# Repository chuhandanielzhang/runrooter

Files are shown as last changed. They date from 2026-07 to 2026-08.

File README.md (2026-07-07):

# Hopper robot runtime (collected runnable files)

This folder gathers the **actually-running** files of the Hopper stack (lower layer +
upper layer + IMU bridge + bring-up scripts). It is a curated copy of the live sources;
build artifacts, logs, caches, and analysis/plot scripts were left out.

## Architecture

```
   PC (this machine)                         Jetson (nvidia@192.168.1.100)
 ┌─────────────────────┐   LCM (multicast)  ┌──────────────────────────────┐
 │ run_modee.py         │ <───────────────> │ hopper_driver (legs/CAN/pad)  │  hopper-driver.service
 │  ModeECore + WBC-QP  │  hopper_data_lcmt  │   src/hardware/*.cpp          │
 │  propeller/leg cmd    │  hopper_imu_lcmt   │                              │
 │                       │  gamepad_lcmt      │ px4_bridge.py (USB MAVLink)  │  px4-bridge.service
 │                       │  motor_pwm_lcmt    │   props=USB  IMU=DDS/TELEM2  │
 └─────────────────────┘                    │  (split: IMU 500, prop 150)  │
                                             │ canable (can0 bring-up)      │  canable.service
                                             └──────────────────────────────┘
```

- **Legs**: 3× AK60 over SocketCAN (`can0`).
- **IMU + propellers**: on the Pixhawk (PX4). As of 2026-07-01 this uses the **SPLIT path**:
  - **IMU** over **DDS/TELEM2** @ **500 Hz**: `xrce-agent.service` (Micro-XRCE-DDS Agent on
    `/dev/ttyTHS1`) + `px4-dds-bridge.service` (`px4_dds_bridge.py --mount-rpy 0,90,0
    --publish-hz 500`) publishes `hopper_imu_lcmt` from PX4 DDS topics. Dedicated UART =
    contention-free. (IMU mount/coordinate unchanged from before — only comms changed.)
  - **Props** over **USB MAVLink**: `px4-bridge.service` runs `px4_bridge.py --no-imu`
    (props ONLY), streaming `MAV_CMD_DO_SET_ACTUATOR` from `motor_pwm_lcmt`. The PC still
    publishes `motor_pwm_lcmt` at the full **500 Hz** control rate, but the MAVLink
    re-stream is capped at **150 Hz** (`--prop-rate 150`): PX4 answers EVERY
    `DO_SET_ACTUATOR` with a `COMMAND_ACK` on this same USB link, so 400 Hz+ floods the link
    with ACKs, PX4 throttles/drops, and the actuator outputs FREEZE ("pwm stuck"). This cap
    is set by the ACK return traffic, NOT by whether the IMU shares the link — 150 Hz
    (6.7 ms) is still far faster than the prop time constant (~40 ms).
  - **Important**: `px4-bridge` MUST keep `--no-imu` so it does NOT also publish
    `hopper_imu_lcmt` — two publishers on one channel fight. To collapse back onto a single
    USB link (props+IMU), drop `--no-imu` and stop `px4-dds-bridge`/`xrce-agent` (keep
    `--prop-rate 150`).
- **Prop output wiring note (2026-06-30)**: the three props now live on the **AUX/FMU**
  group `AUX1/AUX2/AUX3` (moved off MAIN). PX4 output functions: `PWM_AUX_FUNC1=301`
  (Actuator Set 1 -> AUX1), `PWM_AUX_FUNC2=303` (Set3 -> AUX2), `PWM_AUX_FUNC3=302`
  (Set2 -> AUX3) — Set2/Set3 kept swapped so logical Set2/Set3 still drive the same
  physical props as before. `PWM_AUX_MIN/MAX/DIS 1/2/3 = 1000/2000/1000`. `PWM_MAIN_FUNC1/2/3`
  are now `0` (disabled). Driven by the controller via `MAV_CMD_DO_SET_ACTUATOR` (PWM, not
  DShot). NOTE: this Auterion PX4 1.14.3 build has **no `DSHOT_CONFIG` param** so DShot
  is not enable-able without reflashing stock PX4. Re-verify mapping with a per-Set
  low-power spin test after any rewire.

## Folder layout

| Folder | Runs on | What it is |
|---|---|---|
| `lower_driver_jetson/` | Jetson | C++ leg driver (`hopper_driver`). Build with `rebuild.sh`. Source = `Hopper_srbRL`. |
| `upper_controller_pc/` | PC | ModeE controller. `hopper_controller/run_modee.py` + `modee/`. `hopper_lcm_types/` kept as sibling so the `../../hopper_lcm_types/lcm_types` import resolves. |
| `imu_bridge_jetson/` | Jetson | SPLIT path: `px4_dds_bridge.py` (DDS/TELEM2 → `hopper_imu_lcmt` @500Hz) for IMU, `px4_bridge.py --no-imu` (USB MAVLink) for props (re-stream capped @150Hz). Launchers: `run_px4_dds_bridge.sh`, `run_xrce_agent.sh`, `run_px4_bridge.sh`. |
| `services/` | Jetson | systemd units: `hopper-driver`, `xrce-agent`, `px4-dds-bridge` (IMU/DDS), `px4-bridge` (props/USB, `--no-imu`). |
| `scripts/` | PC | `connect_and_start.sh` (one-shot lower-layer bring-up + LCM check) + `hopperleg_README.md`. |
| **`rlmujoco3rsr/`** | PC | **3-RSR 闭环 MuJoCo + MJX/Brax RL**（训练/评估/sim2sim/RL 部署）。见 `rlmujoco3rsr/README.md`。 |

## Bring-up

1. **Lower layer (Jetson)** — usually already installed as services. To (re)build the driver:
   ```bash
   cd lower_driver_jetson && ./rebuild.sh        # -> build/hopper_driver
   ```
   The services run `/home/nvidia/Hopper_srbRL/build/hopper_driver` etc.

2. **Bring everything up + verify (from PC)**:
   ```bash
   bash scripts/connect_and_start.sh             # SSHes to Jetson, starts services, checks CAN + LCM
   ```

3. **Upper layer (PC)**:
   ```bash
   cd upper_controller_pc/hopper_controller
   unset LD_LIBRARY_PATH
   python3 run_modee.py
   ```

## Gamepad map (current logic)

- **X** = enter PD (legs).  **A** = props ON (control_mode).  **B** = stop all (DAMP + props off).
- **LB** (only from the normal hopping cycle): arms a legs-only retraction. It actually
  starts on the **next flight phase, once the leg is back to its original length**
  (`|q_shift| <= switch_arm_l0_tol_m`), runs P1→P2→P3 and settles. A 2nd LB does nothing
  (one-way; use RB to return to hopping).
- **RB** (only after LB has settled at P3): position-controls the legs **up to
  `switch_rb_target_rad`** (P4), holds `switch_rb_settle_s`, then **enters the hopping
  cycle** (ModeE resumes). During the **first hop cycle** after RB (until the 2nd liftoff)
  the propeller PWM is floored at `hop_prop_base_pwm_us` (= 1200; props still spin only if A is ON).

Status line tags: `FLIGHT/STANCE` (normal), `+LB-ARM` (LB armed/waiting), `SW-LB-P1..3`
(retracting), `SW-LB-P3-DONE(RB?)` (settled, RB valid), `SW-RB-P4` (RB pull-up),
`+BASE1200` (post-RB prop base window).

## Key tunables

- Lower layer `qd`: published from a **2-sample central difference of the CAN position**
  (no heavy filtering), see `lower_driver_jetson/src/hardware/hopper_hardware.cpp`.
- Switch-loop / LB / RB / prop-base params: `ModeELCMConfig` at the top of
  `upper_controller_pc/hopper_controller/modee/lcm_controller.py`.

> Note: this is a **collected snapshot**, not a wired-up workspace. The Jetson-side pieces
> still build/run from `~/Hopper_srbRL` (and ROS `~/px4_ws`) on the robot; edit there (or
> sync) for live changes.

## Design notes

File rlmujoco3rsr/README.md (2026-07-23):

# 3-RSR 三旋翼并联跳跃机器人 — 仿真 / RL / Sim2Real 工作包

> **位置**: `robot_runtime/rlmujoco3rsr/`（从 `Hopper-mujoco-standalone/3RSR_package_2` 打包）
> **上层依赖**: 默认用同级 `../upper_controller_pc/`（可用 `CASE_REPO` 覆盖）
> **策略**: `policies/hop_policy_hwcal.params` 等 | **示例 GIF**: `demos/`

闭环并联腿(3-RSR)+ 三旋翼 的 aerial-legged hopper。本包包含 MuJoCo 模型、
MJX+PPO 强化学习训练、CPU 评估、以及通过 LCM 与 Cao(hopperHFAcase2026)上层
控制器互联做 sim2sim 交叉验证 / sim2real 部署的全部脚本。

---

## 1. 系统总览

```
                         ┌─────────────────────────────────────────┐
   高层 (model-based)     │  Cao ModeE SRB/质心 QP 控制器              │
   或 RL 任务策略          │  run_cao_on_our_model.py  /  RL 任务策略    │
                         └───────────────┬─────────────────────────┘
                                         │  LCM:hopper_cmd_lcmt (q_des,kp,kd)
                                         │      motor_pwm_lcmt   (6ch PWM)
                         ┌───────────────▼─────────────────────────┐
   被控对象 (plant)       │  cao_fake_robot.py  (我们的 MuJoCo 模型,     │
   仿真 或 真机           │  说 case 的 LCM 协议)  /  真实机器人 CAN桥     │
                         └───────────────┬─────────────────────────┘
                                         │  LCM:hopper_data_lcmt (q,qd)
                                         │      hopper_imu_lcmt   (quat,gyro)
                                         ▼
                              lcm-spy 可实时监看所有通道
```

两套控制可互换,都说同一套 LCM 协议:
- **Cao SRB QP**(model-based,已验证):`run_cao_on_our_model.py`
- **RL 策略**(本包训练):`rl_lcm_runner.py`

控制架构(分层 RL):
- **端到端策略** `train_hop.py` → `hop_policy_hwcal.params`(会跳,论文托底)
- **分层底层** `train_leg.py` → `leg_policy.params`(纯腿力/速度/腿长跟踪,配 SRB 高层)
- **空翻** `train_flip.py`(实验)

---

## 2. 模型 (`three_leg_3rsr_closed.xml`)

- **3-RSR 并联腿**:3 个髋电机 `ctrl_joint_1/2/3`,万向节被动副 `cross_pin+lower_pin`,
  足端经 `equality connect` 软约束闭环(MJX 原生闭环,非串联近似)。
- **三旋翼**:`prop1/2/3` 120° 对称;3 舵机绕外向 Z 倾转(矢量推力);反扭矩 `gear=±0.018`,
  自旋方向 +/+/−(三旋翼偏航)。
- **执行器(9)**:`ctrl_motor_1/2/3`(位置,kp=100 kv=3,**力矩限幅 ±25 N·m**,
  ctrlrange `[-90°,+60°]`)+ `servo_motor_1/2/3` + `thrust_1/2/3`。
- **传感器**:髋 q/dq、舵机 q、`foot_touch_sensor`(足端法向力,`sensordata[-1]`)。
- 质量:整机 3.75 kg,腿 0.35 kg。

### 腿部运动学(实测,髋角 → 腿长)
| 髋角 | 足端 z (m) | 腿长 base−foot (m) | 状态 |
|---|---|---|---|
| **−90°**(ctrl 下限) | 0.040 | **0.560** | **最长 / 最伸展 / 足最低** |
| −45° | 0.109 | 0.491 | |
| 0° | 0.241 | 0.359 | home 附近(home=−3.5°) |
| +60°(ctrl 上限) | 0.348 | 0.253 | 最短 / 最蜷缩 |

> 单调关系:**髋角越负 → 腿越长**。−90° 即腿最长、足端最低。

### qpos/qvel 布局 (nq=26, nv=24)
```
base free : qpos[0:7]   qvel[0:6]
leg joints: qpos[7:16]  (hip 在 7,10,13)
servos    : qpos[16:19]
foot free : qpos[19:26] (foot_z = qpos[21]) qvel[18:24]
```

---

## 3. 硬件 (sim2real 标定依据)

| 部件 | 型号 | 仿真建模 |
|---|---|---|
| 关节电机 | AK70 级(±25 N·m) | 位置执行器 + 力矩限幅 |
| 旋翼电机 | T-Motor F40 Pro V KV1950 | 一阶滞后 `Tm=0.04s` |
| 桨叶 | Gemfan 1050 三叶 (10×5) | 反扭系数 `gear=0.018` |
| 舵机 | DS3218MG | slew-rate 6.5 rad/s |
| ESC | 4in1 50A (Holybro Kakute H7) | 限流 → 推力封顶,DR ±15% |

---

## 4. 环境配置

### 4.1 RL / 仿真 (Ubuntu + NVIDIA GPU)
```bash
conda create -n rsr python=3.11 -y && conda activate rsr
pip install mujoco mujoco-mjx "jax[cuda12]" brax imageio
python check_mjx.py          # 验证 MJX/GPU
```

### 4.2 LCM 运行时 + Cao 上层依赖
```bash
# 1) LCM (含 lcm-spy / lcm-logger)
pip install lcm           # 或源码编译;lcm-spy 在 ~/.local/bin/
# 2) case 仓库 (Cao 控制器 + LCM 类型),与本包同级:
git clone git@github.com:chuhandanielzhang/hopperHFAcase2026.git \
    /home/abc/Hopper/hopperHFAcase2026
# 本包脚本通过 sys.path 引用:
#   <case>/hopper_lcm_types/lcm_types   (python LCM 消息类型)
#   <case>/hopper_controller            (modee.* 控制器)
```

> Windows 仅查看模型:`py -m mujoco.viewer --mjcf=three_leg_3rsr_closed.xml`

---

## 5. 怎么启动程序

### 5.1 训练 (GPU)
```bash
# 端到端跳跃策略 (9 维: 3髋+3桨+3舵机, 硬件可观测+DR)
XLA_PYTHON_CLIENT_PREALLOCATE=false XLA_PYTHON_CLIENT_MEM_FRACTION=0.6 \
  python -u train_hop.py --hw --dr --timesteps 80000000 \
  --episode_len 1000 --out hop_policy_hwcal.params

# 分层纯腿底层 (3 维: 纯髋; 指令=竖直力+水平速度+腿长)
XLA_PYTHON_CLIENT_PREALLOCATE=false XLA_PYTHON_CLIENT_MEM_FRACTION=0.6 \
  python -u train_leg.py --hw --dr --timesteps 60000000 \
  --episode_len 500 --out leg_policy.params
```

### 5.2 评估 + GIF (CPU)
```bash
# 端到端: <params> <秒> <vx> <vy> <跳高m> [摩擦]
JAX_PLATFORM_NAME=cpu CUDA_VISIBLE_DEVICES="" \
  python _eval_cpu.py hop_policy_hwcal.params 10 0 0 0.08
# 纯腿底层: <params> <秒> <f_cmd 0-1> <腿长m> <vx> <vy>
JAX_PLATFORM_NAME=cpu CUDA_VISIBLE_DEVICES="" \
  python _eval_leg.py leg_policy.params 8 0.6 0.40 0 0
# 输出 *_10s.gif / *_leg.gif + 力跟踪 / GRF / 漂移统计
```

### 5.3 LCM 运行时管线 (sim2sim 验证 / sim2real 部署)

**三个独立终端**(同一台 PC,LCM 走本机组播):

```bash
# 终端 A — 被控对象:我们的模型当 fake robot
cd Hopper-mujoco-standalone/3RSR_package_2
FAKE_TAU=25 python cao_fake_robot.py --duration-s 30 --drop-start-s 1.5

# 终端 B — 上层控制器 (二选一)
#   (B1) Cao SRB QP:
CAO_L0=0.42 CAO_HOP_H=0.20 CAO_MODE=3 CAO_TAU=25 \
  python run_cao_on_our_model.py
#   (B2) RL 策略:
JAX_PLATFORMS=cpu python rl_lcm_runner.py \
  --params hop_policy_hwcal.params --vx 0 --vy 0 --hop-h 0.08

# 终端 C — 实时监看 LCM 通道
~/.local/bin/lcm-spy
#   关注: hopper_data_lcmt(q,qd) hopper_imu_lcmt(quat,gyro)
#         hopper_cmd_lcmt(q_des) motor_pwm_lcmt(PWM)
```

**启动顺序**:先 A(plant)→ 再 B(controller)→ C(lcm-spy)随时开。
Cao 控制器需 gamepad 事件触发:`cao_fake_robot.py` 已模拟 `Y`(站立)→ `X@0.5s`(PD 腿跳)
→ `A@1.0s`(PWMPD 开桨)。

---

## 6. 关键标定值 (sim ↔ 真机坐标对齐)

`deploy_map.py` / `cao_fake_robot.py`(由 `_cao_calib.py` 数值搜索得到,3 电机偏转矢量对齐到 mm):
```
YAW_SIM_FROM_IMU = -120°      # R_sim<-imu = Rz(-120);  v_imu = Rz(+120) v_sim
JOINT_SIGN       = -1         # sim +q 收腿, 控制器 +q 伸腿
Q0_LCM           = 0.0940     # 控制器侧 home 角
HOME_SIM         = -0.060299  # 仿真 home 髋角
q_lcm  = Q0_LCM - (q_sim - HOME_SIM)
tau_sim= -tau_ff_lcm   (±25 N·m)
```
**陀螺符号修正**:真机 Pixhawk 上 `gyro_y` 取反,仿真侧发布时同样 `gyro_pub[1] = -gyro_pub[1]`,
否则 3D 姿态阻尼被反号。

---

## 7. 文件索引

| 文件 | 说明 |
|---|---|
| `three_leg_3rsr_closed.xml` | 主模型(闭环并联腿 + 三旋翼) |
| `train_hop.py` | 端到端跳跃 RL(9 动作) |
| `train_leg.py` | 分层纯腿底层 RL(3 动作,力/速度/腿长跟踪) |
| `train_flip.py` | 空翻 RL(实验,CAV 奖励 + RSI) |
| `_eval_cpu.py` / `_eval_leg.py` / `_eval_flip.py` | CPU 评估 + GIF |
| `cao_fake_robot.py` | 我们的模型当 LCM fake robot(plant) |
| `run_cao_on_our_model.py` | 启动 Cao ModeE QP 控制器(高层) |
| `rl_lcm_runner.py` | RL 策略的 LCM runner(部署) |
| `deploy_map.py` | sim↔真机坐标 / 动作映射 + 足端正运动学 |
| `_cao_calib.py` / `_align_check.py` / `_att_check.py` | 标定 / 对齐 / 姿态诊断 |
| `check_mjx.py` / `sim2sim_check.py` | 环境 / sim2sim 自检 |
| `*.STL` | 机体 / 腿件 / 足 / 桨叶网格 |

---

## 8. 当前状态

- ✅ `hop_policy_hwcal.params`:端到端,原地跳/定速/跳高/软着陆,TWR<1,真机迁移就绪。
- 🔄 `leg_policy.params`:分层底层 v2(竖直力+水平速度+腿长),训练中。
- ⏳ 接 Cao SRB 高层 → 纯腿底层,联调分层栈。
- ⏳ 真机 sim2real 验证(RA-L 命门)。

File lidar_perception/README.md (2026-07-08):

# lidar_perception — Mid-360 巡视 / 建图 / 定位子系统

Livox Mid-360S(网线接 PC `enp44s0`,雷达 IP `192.168.1.186`,host `192.168.1.2`)
→ livox_ros_driver2 → Point-LIO(建图+里程计)→ **LCM 桥** → ModeE 控制器融合 + 巡视。

```
Mid-360S ─eth─> livox_ros_driver2 ─/livox/lidar,/livox/imu─> Point-LIO
                                                    │ /aft_mapped_to_init (odom)
                                                    v
                                    odom_lcm_bridge.py(外参 + FLU/ENU→FRD/NED)
                                                    │ hopper_odom_lcmt
                          ┌─────────────────────────┴──────────────┐
                          v                                        v
     modee/lcm_controller.py + core.py                      patrol.py(航点巡视)
     (XY 位置 + yaw 漂移校正, 慢互补)                          │ hopper_nav_cmd_lcmt
                          ^────────────────────────────────────────┘
```

## 一次性安装(需要密码)

```bash
sudo bash /home/abc/Hopper/lidar_ws/install_ros2_humble.sh   # ROS2 Humble + SDK2 → /usr/local
bash /home/abc/Hopper/lidar_ws/build_ws.sh                   # colcon 编译 driver + point_lio
pip install --user open3d                                    # 仅 relocalize.py 需要
```

## 日常使用

| 场景 | 命令 |
|---|---|
| 建图(手持/推着走) | `bash run_lidar_stack.sh map` → 走一圈 → Ctrl-C → `bash save_map.sh` |
| 巡视/定位(平时) | `bash run_lidar_stack.sh`(桥自动加载重定位变换,若有) |
| 开机重定位到已存地图 | 栈起来后机器人**静止**,`/usr/bin/python3 relocalize.py`,然后重启栈 |
| 记录航点 | 把机器人搬到目标点 → `python3 record_waypoint.py`(写入 `waypoints.yaml`) |
| 巡视 | `python3 patrol.py`(可与控制器同机常驻;手柄 **SELECT** 接入/退出) |

控制器侧(`run_modee.py` 照常启动)自动生效:
- 收到健康的 `hopper_odom_lcmt` 后,`core.py` 用慢互补把 `_p_hat_w` 的 XY 和 yaw
  拉向雷达位姿(z 和速度仍由腿运动学/KF 主导,不受影响);odom 停发/劣化 0.4 s
  自动回纯航位推算。状态行出现 `+LIDAR[x,y]`。
- **SELECT** 切换巡视:`patrol.py` 的速度指令替代右摇杆(上限 0.5 m/s);
  **任何摇杆输入或 B 立即夺回**;nav 指令超时 0.3 s 时保持原地(v=0)。
  状态行出现 `+PATROL(wpN)`。

## 关键文件

| 文件 | 作用 |
|---|---|
| `perception_config.yaml` | 外参(`extrinsic`)、健康门控、巡视参数,**装机后必改 `t_bl_m`/`rpy_deg`** |
| `odom_lcm_bridge.py` | ROS odom → `hopper_odom_lcmt`(坐标变换、杆臂、跳变/超时门控、重定位变换) |
| `patrol.py` | 航点 P 控制 → `hopper_nav_cmd_lcmt`(odom 不健康自动 active=0) |
| `relocalize.py` | 已存地图上的一次性重定位(FPFH+RANSAC → ICP),写 `maps/T_map_odom.npy` |
| `waypoints.yaml` / `record_waypoint.py` | 巡视航点(map 系 XY) |

## 坐标系约定(容易翻车,写死在这)

- **hopper world/map**:NED 风格,**+Z 向下**,x = 上电时机头方向;机体 FRD。
- Point-LIO odom(`camera_init`):重力对齐,**z 向上**。桥内用 `diag(1,-1,-1)`
  翻到 +Z down;雷达 FLU → 机体 FRD 由 `extrinsic.rpy_deg`(顶装正向 = `[180,0,0]`)。
- `extrinsic.t_bl_m` = 雷达原点在机体 FRD 系的坐标(**FRD 的 -Z 是上方**)。

## 上机联调顺序(M6)

1. 雷达装机,量外参填 `perception_config.yaml`;
2. 静置:`run_lidar_stack.sh rviz`,确认 odom 稳定、桥每 5 s 打印的 pos/yaw 合理;
3. 手提机器人走动:确认 `+LIDAR` 出现、`p_hat` 跟随不漂;
4. 原地跳(先低高度):盯桥的 `bad=` 计数和 odom 跳变(触地冲击考验 Point-LIO;
   若发散,调大 `mid360.yaml` 的 `satu_acc`/`satu_gyro` 或给雷达加减振);
5. 录航点 → SELECT 巡视,先 0.2 m/s(`patrol.v_max_mps`)。

## 已知边界

- Mid-360S 需要 SDK2 ≥1.3.1 / driver ≥1.2.6(本仓库克隆版本已满足,dev_type=35)。
- Point-LIO/driver/桥都跑在 PC 上;要无线跳跃需把整套迁到 Jetson(未做,CPU 余量待测)。
- 巡视第一版无避障:航点务必画在空旷处。

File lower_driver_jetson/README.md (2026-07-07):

# HOPPER SRB RL

Pi firmware + PC RL bridge (`rl_deploy/`).

## 1. SCP (PC → PI)

```bash
unset LD_LIBRARY_PATH
rsync -avz --delete \
  --exclude='build/' --exclude='__pycache__/' --exclude='.git/' \
  ./Hopper_srbRL/ pi@PI_IP:~/Hopper_srbRL/
```

## 2. SSH (PC → PI)

```bash
unset LD_LIBRARY_PATH
ssh pi@PI_IP
```

## 3. LCM NETWORK (PI)

```bash
sudo ifconfig eth0 multicast
sudo route add -net 224.0.0.0 netmask 240.0.0.0 dev eth0
sudo ip link set can0 up type can bitrate 1000000 restart-ms 100
```

## 4. BUILD (PI)

```bash
cd ~/Hopper_srbRL
chmod +x rebuild.sh hopper_lcm_types/scripts/make_types.sh
./rebuild.sh
```

## 5. RUN (PI)

```bash
cd ~/Hopper_srbRL
sudo ./build/hopper_driver
```

Xbox: `B` = DAMP · `X` = PD · `X` then `A` = PWMPD · `A` alone is ignored so it never turns the leg off. PC bridge: `Y` = upper-layer reset.

## 6. LCM-SPY (PC)

```bash
cd /path/to/Hopper_srbRL
sudo route add -net 224.0.0.0 netmask 240.0.0.0 dev enp44s0
./hopper_lcm_types/scripts/launch_lcm_spy.sh
```

## 7. RUN RL (PC)

```bash
pip install -r rl_deploy/requirements.txt
cd /path/to/Hopper_srbRL
python rl_deploy/bridge/runner.py --lcm \
  --cmd_vx 0.0 --cmd_vy 0.0 --cmd_apex 0.80 \
  --pwm_max_us 1600 --tau_out_max_nm 20 \
  --steps 999999 --print_every 20 \
  --log_csv logs/clean_rl_hfa_$(date +%Y%m%d_%H%M%S).csv
```

## 8. Propeller Calibration (PC)

Fix the robot/propeller on a bench with a scale/load cell. On the Pi, run
`sudo ./build/hopper_driver`, then press `X` and `A` so prop PWM is enabled.

```bash
cd /path/to/Hopper_srbRL
python rl_deploy/scripts/calibrate_prop_pwm.py --armed \
  --props all --pwm_start 1050 --pwm_stop 1600 --pwm_step 50 \
  --units g --out logs/prop_pwm_calibration_$(date +%Y%m%d_%H%M%S).csv
```

## DEMO

walk-stop

rollout

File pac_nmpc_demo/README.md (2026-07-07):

# PAC-NMPC Hopping Demo (isolated)

Joseph Moore (JHU) 风格的 **PAC-NMPC**(采样式随机 NMPC + PAC 置信上界,
Polevoy/Kobilarov/Moore, RA-L 2023, arXiv:2210.08092)应用到 Pro-OMEGA2 跳跃机器人,
在 MuJoCo 中闭环运行。

**本文件夹与 Jetson/PC 运行栈完全隔离**:不 import、不修改
`robot_runtime/upper_controller_pc`、`lower_driver_jetson` 等任何在跑的文件。
需要的约定/几何/电机表全部以"快照拷贝"方式放在 `hopper_pac/` 内。

## 接口与坐标 = Jetson 栈

`hopper_pac/sim.py` 复刻了 `mujoco_lcm_fake_robot.py`(CASE 仿真 parity 层)的
IO 语义,serial plant 路径:

| 信号 | 约定 |
|---|---|
| `q/qd` (3,) | LCM 关节 [roll, pitch, shift],serial: `q_sign=1, q_offset=0` |
| `tau_ff` (3,) | 关节前馈:roll/pitch 力矩 (Nm, ±27),shift 为直线力 (N, ±2500) |
| `quat` | wxyz, body→world |
| `gyro` | 体坐标角速度 |
| `acc` | −(比力):静止 `[0,0,-9.81]`,自由落体 `[0,0,0]` |
| `pwm_us` (6,) | ESC PWM;实测 1950KV 电机表 → 推力,沿体 +Z 施加在臂端 |
| 桨臂映射 | RED/GREEN/BLUE,GREEN 朝 +X;PWM 通道 per arm = (2,1,3) |
| 机身系 | +X 前, +Y 左, +Z 上;世界 +Z 上 |

模型 = `model/hopper_serial.xml`(CASE 同款,连 mesh 一起拷贝)。

## 结构

```
hopper_pac/
  conventions.py   # 所有与运行栈一致的常量/坐标(快照,注明出处行号)
  leg.py           # serial 腿 FK/IK/Jacobian/GRF→tau (核对 core.py _serial_leg_fk_jac)
  motor_table.py   # PWM<->推力表 (快照自 motor_utils.py)
  sim.py           # MuJoCo plant, step(tau, pwm)->SensorData;真实不确定性注入在这里
  srb_rollout.py   # 向量化随机 SRB rollout:每个样本自己触发 touchdown(多峰接触时序)
  pac_nmpc.py      # PAC-NMPC:采样分布 -> 多世界评估 -> PAC 上置信界 -> elite 更新
  controller.py    # 50Hz PAC-NMPC 外环 + 500Hz 内环(GRF→tau / Raibert / 桨姿态PD)
run_demo.py        # 闭环 demo / Monte-Carlo / push / 录像
plot_results.py    # 两张主图:episode 时序 + certificate 校核
```

分层与真机一致:外环出 wrench(50 Hz,= 运行栈 `_mpc_f_ref_cache` 那条 MPC→QP 通路的位置),
内环 500 Hz 执行(对应 WBC-QP 层,含摩擦锥 + fz 下限的可行性保护)。

## 跑法

```bash
cd pac_nmpc_demo
python3 run_demo.py                      # PAC-NMPC,名义 plant
python3 run_demo.py --deterministic      # 基线:同一采样器,关掉不确定性
python3 run_demo.py --hard               # 恶劣真机参数(低摩擦/地面偏移/载荷/弱桨)
python3 run_demo.py --trials 10          # Monte-Carlo 随机 plant -> 成功率
python3 run_demo.py --push 25            # 每 2.5s 一次 25N×0.1s 随机方向推
python3 run_demo.py --video out/x.mp4    # 录像
python3 plot_results.py --trials 8       # 生成 out/timeseries.png, out/bound_check.png
```

## 当前状态(2026-07-04)

- 闭环稳定跳:名义 plant 4/4 seed,10 s 内 ~16 hops,|roll|,|pitch| < 2°。
- Monte-Carlo 随机 plant(μ∈[0.1,0.9]、地面高度 ±3cm、载荷 ≤1kg、推力 ±10%、陀螺噪声):
  PAC 10/10,确定性基线也 10/10 —— **当前扰动分布下两者尚未拉开差距**,
  要展示 PAC 的差异化需要更极端的多峰分布(如双峰地面高度/冰面摩擦)+ push 组合。
- push:25 N 可恢复;40 N 会摔(内环姿态权限所限)。
- 求解:纯 NumPy CPU,外环单次 ~50 ms(=20Hz 实时);500Hz tick 均值 5ms。
  搬 GPU/torch 采样是下一步(Moore 原文即 GPU 并行)。

## 与"投名状"的对应关系

- 方法主体 = PROPS 式采样策略分布优化 + 逐次最小化 PAC 上置信界(`pac_nmpc.py`),
  证书 = 每次 solve 输出的 `bound`(见 `out/timeseries.png` 第三栏)。
- 新场景 = 混合接触:rollout 里每个采样世界自己触发 touchdown/liftoff,
  接触时序不确定性天然多峰 —— 这是 Moore 原文(光滑固定翼/车)没有的疆域。
- 下一步(按优先级):
  1. torch/GPU 化 rollout(3070 Ti),把 S×M 提到 10^4 量级,bound 收紧;
  2. 用真机 CSV log 拟合 `RolloutUncertainty`(接触时序方差/滑移/推力误差);
  3. 设计"多峰专属"场景(双峰地面、冰面)拉开 PAC vs 确定性的消融差距;
  4. 真机部署:外环替换 `f_ref` 通路,内环沿用现有 WBC-QP(不改现有文件,新开分支)。

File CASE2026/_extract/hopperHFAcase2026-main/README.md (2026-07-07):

# hopperHFAcase2026

Cao's classical ModeE controller for the hybrid hopper, plus the paper-relevant
experiment logs. This is a curated, self-contained snapshot for the paper:
the low-level C++ leg driver, the high-level Python controller, and the exact
logs the paper figures are generated from.

## Layout

```
.
├── main.cpp  CMakeLists.txt  rebuild.sh   # low level: C++ leg driver (hopper_driver)
├── src/  include/                          #   sources / headers
├── xbox_driver/                            #   gamepad input
├── hopper_lcm_types/                       #   LCM message definitions (.lcm + generated cpp)
├── model/                                  #   MuJoCo XML + meshes (used by the sim/upper layer)
├── hopper_controller/                      # high level: Cao ModeE controller
│   ├── run_modee.py                        #   main controller entry point
│   ├── modee/                              #   ModeE state machine + control
│   ├── forward_kinematics.py
│   ├── mujoco_lcm_fake_robot.py            #   sim-in-the-loop fake robot over LCM
│   ├── plot_paper_figures.py               #   paper figures  (reads ../logs/test2_1.csv)
│   ├── plot_paper_v2.py                    #   paper figures v2 (reads ../logs/*.csv)
│   └── record_modee_serial_*.sh            #   data-recording helpers
└── logs/                                   # paper-relevant logs (the ones the figures use)
    ├── test2_1.csv                         #   -> plot_paper_figures.py
    ├── tt5_20260228_0110.csv               #   -> plot_paper_v2.py (Exp1)
    ├── caotest3_20260226_1053.csv          #   -> plot_paper_v2.py (Exp2, outdoor)
    ├── caopengtask1_20260226_1055.csv      #   -> plot_paper_v2.py (Exp3)
    └── figs/                               #   pre-rendered reference figures (PNG)
```

The plot scripts read CSVs from `../logs/` relative to themselves, so the repo
is self-contained — no absolute paths required.

## Build (low level, legs-only)

The driver is the Jetson + Pixhawk legs-only build: 3x AK60 leg motors over
SocketCAN (`can0`). IMU and propeller PWM are owned by the Pixhawk, not this
binary.

```bash
chmod +x rebuild.sh hopper_lcm_types/scripts/make_types.sh
./rebuild.sh
sudo ./build/hopper_driver
```

## Reproduce paper figures

```bash
cd hopper_controller
python3 plot_paper_figures.py     # writes ../logs/paper_figs/
python3 plot_paper_v2.py          # writes ../logs/paper_figs_v2/
```

## Notes

- Only the four CSVs the paper figures actually consume are committed here; the
  full raw log archive (~20 GB) is intentionally excluded.
- Legacy Velox-F7 tooling (`tri_balance`, `motor_id_seq`) is retired and not
  built; see the commented blocks in `CMakeLists.txt`.

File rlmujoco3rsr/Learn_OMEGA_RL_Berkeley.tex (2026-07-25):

% ============================================================================
%  OMEGA × CS285 联合讲义（小白详细扩展版）
%  课件对照：UC Berkeley CS285 Deep RL (Sergey Levine)
%    https://rail.eecs.berkeley.edu/deeprlcourse/
%  论文：Zhang et al. Learning to Hop... Parallel Mechanism (OMEGA)
%  编译：xelatex Learn_OMEGA_RL_Berkeley.tex  （两遍）
% ============================================================================
\documentclass[11pt,a4paper]{article}

\usepackage[UTF8]{ctex}
\usepackage{amsmath,amssymb,amsfonts,bm}
\usepackage{graphicx}
\usepackage{hyperref}
\usepackage{geometry}
\usepackage{enumitem}
\usepackage{tikz}
\usetikzlibrary{arrows.meta,positioning,calc}
\geometry{margin=2.1cm}
\hypersetup{colorlinks=true,linkcolor=blue,urlcolor=blue}

\title{\textbf{CS285 课件 $\times$ OMEGA 论文}\\[0.35em]
\large 强化学习零基础详细讲义\\[0.2em]
\normalsize （并联单足跳跃机器人 RL 精读）}
\author{教学笔记\\
\small 课件：Berkeley CS285 Deep RL（Levine）\quad
论文：Zhang et al., \textit{Learning to Hop for a Single-Legged Robot
with Parallel Mechanism}}
\date{}

\newenvironment{csbox}[1][CS285 课件]{%
  \par\medskip\noindent\fbox{\begin{minipage}{0.96\linewidth}
  \textbf{【课件・#1】}\par\smallskip\begingroup\small}%
  {\endgroup\end{minipage}}\par\medskip}
\newenvironment{paperbox}[1][OMEGA 论文]{%
  \par\medskip\noindent\fbox{\begin{minipage}{0.96\linewidth}
  \textbf{【论文・#1】}\par\smallskip\begingroup\small}%
  {\endgroup\end{minipage}}\par\medskip}
\newenvironment{keyidea}[1][先记住]{%
  \par\medskip\noindent\fbox{\begin{minipage}{0.96\linewidth}
  \textbf{【#1】}\par\smallskip}%
  {\end{minipage}}\par\medskip}
\newenvironment{example}[1][例子]{%
  \par\medskip\noindent\fbox{\begin{minipage}{0.96\linewidth}
  \textbf{【#1】}\par\smallskip}%
  {\end{minipage}}\par\medskip}
\newenvironment{warnbox}[1][易混]{%
  \par\medskip\noindent\fbox{\begin{minipage}{0.96\linewidth}
  \textbf{【#1】}\par\smallskip}%
  {\end{minipage}}\par\medskip}
\newenvironment{bridge}[1][课件 $\leftrightarrow$ 论文对接]{%
  \par\medskip\noindent\rule{\linewidth}{0.4pt}\par\noindent
  \textbf{#1}\par\smallskip}%
  {\par\noindent\rule{\linewidth}{0.4pt}\par\medskip}
\newcommand{\csref}[1]{\texttt{[CS285~#1]}}
\newcommand{\papref}[1]{\texttt{[论文~#1]}}

\begin{document}
\maketitle

\begin{abstract}
\noindent
本讲义\emph{严格按} UC Berkeley \textbf{CS285} 的课程序列展开，
每一讲都给出：
(1) 课件在讲什么；(2) 公式与直觉；(3) OMEGA 论文对应段落/公式/图；
(4) 你该会复述的句子。面向\textbf{RL 零基础}。
课件主页：\url{https://rail.eecs.berkeley.edu/deeprlcourse/}。
本地论文稿：\texttt{Hopper-mujoco-standalone/ppopaper}。
\end{abstract}

\tableofcontents
\newpage

%==============================================================================
\part{总路线：课件目录如何映射到论文}
%==============================================================================

\section{对照总表（请贴墙上）}

\begin{center}
\small
\begin{tabular}{@{}p{3.6cm}p{5.0cm}p{5.0cm}@{}}
\hline
\textbf{CS285 讲次（典型）} & \textbf{你要学会的概念} & \textbf{OMEGA 落点} \\
\hline
Lec1--2 Intro / Supervised behavior
& 试错学习 vs 模仿学习 & 为什么不用纯专家示教，而用奖励 \\
\hline
Lec4 Intro to RL
& Agent, MDP 组件, episode & §III 总览；Isaac 循环 \\
\hline
Lec5 Policy Gradients
& $\pi_\theta$, $J(\theta)$, REINFORCE & 策略输出期望角；优化长期跳得好 \\
\hline
Lec6 Actor--Critic
& $V$, $A$, actor/critic & 非对称 Actor--Critic，Fig.\,4 \\
\hline
Lec7--8 Value / Q（可略读）
& 价值在干嘛 & Critic 估 $V$；他们不用 DQN \\
\hline
Lec9 Advanced PG / PPO
& PPO clip / TRPO 直觉 & 正文：Isaac Gym + PPO \\
\hline
Lec10 Optimal Control
& model-based 控制 & 对比：SLIP/Cao QP vs RL；底层 PD \\
\hline
Lec11--12 Model-based RL（可选）
& 学模型再规划 & 论文\emph{不}走这条；他们走 model-free \\
\hline
Lec18 VAE / Generative
& latent、重建、KL & $\beta$-VAE encoder--decoder，Fig.\,4 \\
\hline
Lec22 Transfer
& sim-to-real, DR & §III Domain Rand；§V torque mapping \\
\hline
\end{tabular}
\end{center}

\begin{keyidea}
学法：先读本讲义一讲 $\to$ 打开 CS285 对应视频/slide 扫一遍（可 1.5 倍速）
$\to$ 立刻读论文对应小节，用荧光笔标公式编号。
\end{keyidea}

\begin{paperbox}[摘要里的问题陈述]
论文 abstract 三点困难：
(1) 并联难仿真；(2) 长空欠驱动；(3) 奖励稀疏。
对策：long-history；serial 简化；torque-level conversion。
整份讲义就是把这三点翻译成 CS285 语言。
\end{paperbox}

\newpage
%==============================================================================
\part{Part I —— CS285 Lec4：强化学习入门（零基础）}
%==============================================================================

\section{Lec4.1 \; 什么是强化学习（对照监督）}

\begin{csbox}[Lec4 Anatomy of RL]
课件指出：RL 算法收集数据（交互）$\to$ 用数据改进策略或价值。
数据类型不是「$(x,y)$ 标签」，而是「轨迹：状态、动作、奖励」。
\end{csbox}

\begin{example}[监督学习]
给出很多「传感器读数 $\to$ 人手动示范的电机角」，拟合网络。
需要大量示范；示范越难（跳跃），越贵。
\end{example}

\begin{example}[强化学习]
不给标准动作；给规则：「跟上 $0.2$\,m/s、不倒」。
机器人自己试，好就奖励高。代价是样本多、奖励难调。
\end{example}

\begin{bridge}
课件问：rl 适合何时场景？高频最优解难写、交互可仿真。\\
论文答：并联动力学难准写 + 连续跳跃难调参 $\Rightarrow$ 用 RL。
同时他们用底层 PD（频域分离）——课件 Lec10「把高层决策与低层控制分层」。
\end{bridge}

\section{Lec4.2 \; 五个名词 + 回路图}

\textbf{Agent}：决策器。\quad
\textbf{Environment}：Isaac/真机。\quad
\textbf{State $s$}：完整真相。\quad
\textbf{Observation $o$}：可测子集。\quad
\textbf{Action $a$}：控制量。\quad
\textbf{Reward $r$}：标量反馈。\quad
\textbf{Policy $\pi$}：观测$\mapsto$动作。

\begin{center}
\begin{tikzpicture}[
  box/.style={draw,rounded corners,align=center,inner sep=4pt,font=\small}]
\node[box,fill=blue!8] (obs) {观测 $o_t$\\Eq.\,8};
\node[box,right=1.1cm of obs,fill=orange!12] (pi) {策略 $\pi_\theta$\\Actor};
\node[box,right=1.1cm of pi,fill=green!10] (act) {动作 $a_t$\\期望角};
\node[box,right=1.1cm of act,fill=gray!12] (env) {环境\\Serial $+$ 映射};
\node[box,below=1.0cm of env,fill=yellow!15] (r) {$r_t$, $o_{t+1}$};
\draw[-Latex] (obs)--(pi); \draw[-Latex] (pi)--(act);
\draw[-Latex] (act)--(env); \draw[-Latex] (env)--(r);
\draw[-Latex] (r)-| node[near start,left,font=\scriptsize]{下一拍} (obs);
\end{tikzpicture}
\end{center}

\begin{paperbox}[§III Framework]
「policy receives history of proprioceptive measurements；
critic has ground truth；VAE-style encoder；MSE velocity；Isaac+PPO。」
上面这句话几乎是 Fig.\,4 的文字版。
\end{paperbox}

\section{Lec4.3 \; Episode、horizon、折扣回报}

一局（episode）：重置到倒下/超时。\\
即时奖励 $r_t$；回报
\[
G_t=r_t+\gamma r_{t+1}+\gamma^2 r_{t+2}+\cdots,\quad \gamma\in[0,1).
\]

\begin{csbox}[Lec4 Value]
$V^\pi(s)=\mathbb{E}[G_t\mid s_t=s]$：从这个状态按 $\pi$ 玩下去平均能得多少分。
\end{csbox}

\begin{example}
起跳「疼」（落地冲击惩罚）但总回报高——因为后面连续跳成功。
所以\textbf{不能}只贪每一步最大 $r$。
\end{example}

\newpage
%==============================================================================
\part{Part II —— MDP / POMDP（课件核心＋论文设定）}
%==============================================================================

\section{Lec4.4 \; MDP 五元组}

\begin{csbox}[Lec4 MDP]
$\mathcal{M}=(\mathcal{S},\mathcal{A},P,r,\gamma,\rho_0)$。
转移 $s_{t+1}\sim P(\cdot|s_t,a_t)$；奖励 $r_t=r(s_t,a_t)$。
目标：$\max_\theta J(\theta)=\mathbb{E}_{\tau\sim\pi_\theta}[\sum_t\gamma^t r_t]$。
\end{csbox}

\textbf{马尔可夫性}：有了完整 $s_t$，未来与更早历史无关。

\section{Lec4.5 \; POMDP —— 论文显式采用}

\begin{csbox}
真实机器人几乎总是 POMDP：测量噪声、不可见接触力/滑移/速度。
习惯解法：堆栈历史、RNN、或学 latent state。
\end{csbox}

\begin{paperbox}[§III ``We formulate this control problem as a POMDP'']
观测 Eq.\,8（不给真线速度）：
\begin{equation}
o_t=\big[
\hat q_{m,t}^{\mathcal{P}},\;
\hat q_{[r,p,y],t},\;
\hat{\dot q}_{[r,p,y],t},\;
\cos q_{\mathrm{phase}},\;
\sin q_{\mathrm{phase}},\;
\dot q_{[x,y]}^{d},\;
T,\;
a_{t-1}^{\mathcal{P}}
\big].
\tag{论文 Eq.8}
\end{equation}
并用 $H=5$ 历史输入 Encoder（约 $0.1$\,s）。
\end{paperbox}

\subsection*{逐项人话（Eq.\,8）}

\begin{center}
\small
\begin{tabular}{@{}p{3.3cm}p{10.2cm}@{}}
\hline
符号 & 解释 \\
\hline
$\hat q_m^{\mathcal{P}}$ &
三电机角，\emph{并联坐标}。注意：仿真里身子是串联，但喂给网络前先换成并联角。 \\
姿态 / 角速度 & IMU；真机可得。 \\
$\cos,\sin$ phase &
开环时钟：支撑/腾空参考。$q_{\mathrm{phase}}$ 在 $[-2\pi,2\pi]$ 扫，
$<0$ stance，$>0$ swing（论文原文）。 \\
$\dot q^d$, $T$ & 命令：水平速度 + 周期（任务条件）。 \\
$a_{t-1}$ & 上一步输出，抗抖。 \\
\hline
\end{tabular}
\end{center}

\begin{warnbox}
Phase \emph{不是}两个控制器切换开关；是观测与奖励里的参考节律。
真正一个 Actor 全程输出 $a_t$。
\end{warnbox}

\section{Lec4.6 \; 欠驱动：为何跳跃「更 POMDP」}

\begin{paperbox}[§II-D Underactuation]
飞行 $0.2$--$0.4$\,s 几乎只受重力；支撑相才有大力。
控制器必须在空中就「为落地准备」。假设：难点在长欠驱动窗口；
需要从历史估计尤其 $z$ 向速度。
\end{paperbox}

\begin{bridge}
\textbf{课件语言}：长 horizon credit assignment + partial observability。\\
\textbf{论文语言}：prolonged aerial phase；history encoder + explicit $v$ estimate。
\end{bridge}

\newpage
%==============================================================================
\part{Part III —— 动作、底层 PD、奖励（分层控制）}
%==============================================================================

\section{动作空间：策略输出「目标角」}

\begin{paperbox}[§III Action]
Actor $@50$\,Hz 输出并联期望角 $a_t$。\\
PD $@500$\,Hz（训练叙述）或文中也写 $200$\,Hz：
\[
\tau^{\mathcal{P}}=K_p(a_t-q^{\mathcal{P}})-K_d\dot q^{\mathcal{P}},
\quad K_p=20,\; K_d=0.5.
\tag{论文 Eq.9c}
\]
仿真中再映射成 $\tau^{\mathcal{S}}$；真机直接用 $\tau^{\mathcal{P}}$。
\end{paperbox}

\begin{csbox}[Lec10 Optimal Control 直觉]
工业界常态：RL/规划输出参考；高频伺服（PD/阻抗）执行。
这样 RL 不必在 kHz 力矩环上做探索。
\end{csbox}

\begin{keyidea}
把系统想成两层：上层 RL「慢思考」；下层 PD「快执行」。
\end{keyidea}

\section{奖励设计（课件：「奖励塑造」）}

\begin{csbox}
奖励工程 = 定义任务。过稀：学不动。过偏：reward hacking。
课件反复强调 reward 是归纳偏置。
\end{csbox}

\begin{paperbox}[§III Rewards]
三类：tracking / phase schedule / auxiliary（细节在附录）。
即：跟指令；跟节律接触；别乱动。
\end{paperbox}

\begin{example}
若只奖励「高度最大值」偶发一次，几乎无梯度（稀疏）。
加相位匹配与速度跟踪后，每一步都有学习信号（dense shaping）。
\end{example}

\newpage
%==============================================================================
\part{Part IV —— Policy Gradient \& PPO（课件 Lec5 / Lec9）}
%==============================================================================

\section{Lec5 \; 策略梯度在说什么}

\begin{csbox}[Lec5]
目标 $J(\theta)=\mathbb{E}_{\tau\sim\pi_\theta}[R(\tau)]$。\\
策略梯度定理（直觉版）：
\[
\nabla_\theta J(\theta)=\mathbb{E}\Big[\sum_t\nabla_\theta\log\pi_\theta(a_t|s_t)\, \Psi_t\Big],
\]
$\Psi_t$ 可用回报 $G_t$、或优势 $A_t$ 等。
「好动作提高 log 概率」。
\end{csbox}

\textbf{高方差问题}：只用整条回报估 $\Psi$，噪声大。$\Rightarrow$ 引入 baseline / Critic。

\section{Lec6 \; Actor--Critic}

\begin{csbox}[Lec6]
Actor：$\pi_\theta$。Critic：$\hat V_\phi$。\\
优势例子（GAE 等）：$\hat A_t \approx r_t+\gamma\hat V(s_{t+1})-\hat V(s_t)$。\\
用 $\hat A$ 减方差；有偏但实用（bias--variance）。
\end{csbox}

\begin{paperbox}[§III asymmetric AC]
Actor 看可部署信息；Critic 看「actor 观测 + 仿真真值」。
这是腿足常见的特权学习（privileged learning），不是标准对称 AC 课本最小例子，
但是 Lec6 思想的直接工程加强。
\end{paperbox}

\section{Lec9 \; PPO（论文优化器）}

\begin{csbox}[Advanced Policy Gradients]
PPO 用概率比
$r_t(\theta)=\pi_\theta(a_t|s_t)/\pi_{\theta_{\mathrm{old}}}(a_t|s_t)$，
裁剪避免更新过大：
\[
L^{\mathrm{CLIP}}=\mathbb{E}\big[\min(
r_t\hat A_t,\;
\mathrm{clip}(r_t,1-\epsilon,1+\epsilon)\hat A_t)\big].
\]
实现上：并行环境采大量轨迹，多 epoch 更新，加 value loss、entropy。
\end{csbox}

\begin{paperbox}
「training is done in Isaac Gym using PPO」。\\
大规模并行（课件也强调 sample efficiency / throughput）是腿足可训的关键工程点。
\end{paperbox}

\begin{keyidea}
你不必手推 PPO；你要能说：论文 = \textbf{model-free on-policy} + PPO + 并行仿真。
\end{keyidea}

\newpage
%==============================================================================
\part{Part V —— 表示学习（课件 Lec18 × 论文 Fig.4）}
%==============================================================================

\section{为何要「压缩历史」}

输入：最近 $H$ 帧观测拼接，维度高、冗余。\\
需要短向量 $\mu_t$ 总结「对跳跃有用的记忆」。

\section{VAE / $\beta$-VAE（对上课件生成模型）}

\begin{csbox}[Lec18 Variational Inference]
VAE：Encoder $q(\mu|h)$，Decoder $p(o|\mu)$。\\
损失 $\approx$ 重建误差 $+\;\beta\,\mathrm{KL}(q\|p)$。
$\beta$ 控压缩强度。
\end{csbox}

\begin{paperbox}[Fig.\,4 文字]
Encoder $\Phi$：历史 $o_{t-1:t-H}$ $\to$ latent $\mu_t$，外加速度/接触估计头。\\
Decoder $\beta$：$\mu_t\to\hat o_{t+1}$。按 $\beta$-VAE：重建 + KL。\\
Actor：$\pi(a_t\mid \mu_t,\hat{\dot q}_t,o_t)$。
\end{paperbox}

\section{显式速度回归（辅助任务）}

\begin{paperbox}
$\hat{\dot q}_{[x,y,z]}$ 用 MSE 拟合仿真真值。\\
消融 §IV：
\begin{itemize}
  \item Proposed = latent + 显式估计；
  \item State Estimation Only；
  \item Latent Only。
\end{itemize}
结论：长空时显式速度\textbf{至关重要}；纯 latent 不够。
\end{paperbox}

\begin{bridge}
\textbf{课件}：multi-task / auxiliary losses 改善表示。\\
\textbf{论文}：控制主损失（PPO）+ VAE + MSE 速度头。
\end{bridge}

\begin{center}
\begin{tikzpicture}[box/.style={draw,align=center,rounded corners,font=\scriptsize,inner sep=3pt}]
\node[box,fill=blue!10] (h) {历史 $H=5$};
\node[box,right=0.8cm of h,fill=blue!15] (e) {$\Phi$ Encoder};
\node[box,above right=0.25cm and 0.7cm of e,fill=green!12] (m) {$\mu_t$};
\node[box,below right=0.25cm and 0.7cm of e,fill=green!12] (v) {$\hat v$};
\node[box,right=2.6cm of e,fill=orange!15] (pi) {$\pi$};
\node[box,right=0.7cm of pi,fill=red!12] (a) {$a_t$};
\node[box,below=0.9cm of e,fill=gray!15] (d) {$\beta$ Decoder $\hat o_{t+1}$};
\node[box,below=0.9cm of pi,fill=purple!12] (c) {Critic (+特权)};
\draw[-Latex] (h)--(e); \draw[-Latex] (e)--(m); \draw[-Latex] (e)--(v);
\draw[-Latex] (e)--(d); \draw[-Latex] (m)|-(pi); \draw[-Latex] (v)|-(pi);
\draw[-Latex] (pi)--(a); \draw[-Latex,dashed] (c)--(pi);
\end{tikzpicture}
\end{center}

\newpage
%==============================================================================
\part{Part VI —— Sim-to-Real（课件 Transfer $\times$ 论文 §III-C / §V）}
%==============================================================================

\section{课件视角：两种缺口}

\begin{csbox}[Transfer / DR]
(1) \textbf{动力学缺口}：质量摩擦等 $\Rightarrow$ Domain Randomization。\\
(2) \textbf{模型结构缺口}：并联仿不准 $\Rightarrow$ 换模板 / 特殊转换。
论文两刀都用了。
\end{csbox}

\section{Domain Randomization（论文明文）}

\begin{paperbox}
随机动力学与控制参数；地形：缓坡、糙坡、台阶（Fig.\,5）。\\
真机：平地 + $10^\circ$ 坡；相对 SLIP 基线存活时间与位置误差更优（Table\,I）。
\end{paperbox}

\section{Serial Template —— 结构性 sim2real}

\begin{paperbox}[§II-C / §III-C]
为避免直接仿 3D 并联，建 DoF 相同的串联模板 $S$：
Roll--Pitch--Shift。工作空间相近；动力学在 Isaac 可训。
\end{paperbox}

你本地可看：
\texttt{hopper\_serial.urdf} / \texttt{hopperHFAcase2026/model/hopper\_serial.xml}。

\section{Eq.\,9 逐行精读（务必过一遍）}

\begin{subequations}
\begin{align}
q^{\mathcal{P}} &= IK^{\mathcal{P}}\!\big(FK^{\mathcal{S}}(q^{\mathcal{S}})\big)
\tag{9a}\\
\dot q^{\mathcal{P}} &= (J^{\mathcal{P}})^{-1} J^{\mathcal{S}}\dot q^{\mathcal{S}}
\tag{9b}\\
\tau^{\mathcal{P}} &= K_p(a_t-q^{\mathcal{P}})-K_d\dot q^{\mathcal{P}}
\tag{9c}\\
\tau^{\mathcal{S}} &= (J^{\mathcal{S}})^{T}(J^{\mathcal{P}})^{-T}\tau^{\mathcal{P}}
\tag{9d}
\end{align}
\end{subequations}

\begin{description}[style=nextline,leftmargin=1.6cm]
\item[(9a)] 串联位形 $\xrightarrow{\text{FK}}$ 脚点 $\xrightarrow{IK^{\mathcal{P}}}$ 等价并联角。策略看见并联角。
\item[(9b)] 速度层同样换坐标（雅可比）。
\item[(9c)] PD 在并联误差上算「并联世界该有的力矩」。
\item[(9d)] 同一只脚的力 $f$：$\;\tau=J^\top f\;\Rightarrow$
可从 $\tau^{\mathcal{P}}$ 换 $\tau^{\mathcal{S}}$（静力虚功）。
\end{description}

\begin{keyidea}
策略接口永远是「并联」；仿真动力学是「串联」。映射垫在中间。
部署：垫片拿走。
\end{keyidea}

\section{三种基线（§V）——考试必背}

\begin{center}
\small
\begin{tabular}{@{}p{3.5cm}p{5cm}p{5cm}@{}}
\hline
方法 & 做法 & 论文结果 \\
\hline
Torque mapping（本文） & 训时 Eq.\,9；部署无映射 & 成；力矩曲线 sim≈real \\
Joint target mapping & 只做角度运动学 remap & 败 \\
Parallel MuJoCo 直接训 & 硬仿 3-RSR & 仿真不可靠，败 \\
\hline
\end{tabular}
\end{center}

\begin{bridge}
\textbf{课件}：model mismatch 不能只靠「看起来差不多的状态映射」。\\
\textbf{论文}：力/力矩层对齐比位置层对齐更贴近接触动力学。
\end{bridge}

\newpage
%==============================================================================
\part{Part VII —— Model-free vs Model-based（Lec10--12 对照）}
%==============================================================================

\section{论文选择 model-free；底层仍有模型式 PD}

\begin{csbox}[Lec10--12]
Model-based：学/用 $P$，再规划。\\
Model-free：直接学 $\pi$ 或 $Q$。\\
还有混用。最优控制（LQR/MPC/QP）属「有模型」。
\end{csbox}

\begin{paperbox}
骨干：model-free PPO（无显式学 $P$）。\\
但：腿有解析 FK/IK/J（式 1--7）；底层 PD；对比基线是 SLIP model-based。\\
即：\textbf{混合系统}——RL 决策 + 经典低层 + 运动学工具。
\end{paperbox}

\begin{example}[和你们实验室栈]
Cao HFA：整段偏 model-based QP。\\
OMEGA：整段偏 RL。\\
你们 MJX 路线：RL + 原生并联模型（与 OMEGA「避开并联仿真」相反）。
\end{example}

\newpage
%==============================================================================
\part{Part VIII —— 把一局训练「逐步播放」}
%==============================================================================

\section{伪代码（对照课件 ``anatomy of RL algorithm''）}

\begin{verbatim}
初始化 Actor π_θ, Critic V_φ, Encoder Φ, Decoder β
循环 iter = 1..N:
  用当前 π 在 Isaac 并行环境 rollout:
    读 serial 状态 q^S
    用 (9a)(9b) 得 q^P, dq^P，拼 o_t（Eq.8）
    历史窗口 H=5 → Φ → (μ, vhat)
    a ~ π(.|μ,vhat,o); PD → τ^P → (9d) → τ^S → 步进物理
    记录 r, 存缓冲；VAE 重建目标 o_{t+1}；速度 MSE 目标 v_gt
  用 PPO 更新 π、V（非对称观测）
  更新 Φ,β（重建+KL）与速度头（MSE）
导出 Actor（及必要的估计头）到真机；去掉 (9a)(9b)(9d)
\end{verbatim}

\begin{paperbox}[频率]
策略 $50$\,Hz；PD $200$--$500$\,Hz（文中两处数字，抓住「慢策略快伺服」即可）。
\end{paperbox}

\newpage
%==============================================================================
\part{Part IX —— 消融、真机、你怎么自学}
%==============================================================================

\section{§IV 消融：用课件语言复述}

「表示是否包含任务关键物理量」决定长时部分观测控制的成败。\\
仅生成式重建（latent）不保证 $v_z$ 可解码成控制有用信号 $\Rightarrow$ 要 auxiliary supervised head。

\section{§V 真机：zero-shot}

\begin{paperbox}
同策略 $\beta=0.005$ 平地 $0.2$\,m/s、$T\approx0.38$\,s；无微调。\\
Fig.\,13：映射后仿真力矩与真机力矩后期形态接近。
\end{paperbox}

\section{小白 14 日学习计划（课件+论文）}

\begin{enumerate}[leftmargin=*]
  \item Day1--2：本讲义 Part I--II + CS285 Lec4 视频；只求懂 MDP/POMDP。
  \item Day3--4：Part III--IV + Lec5/6；能复述 Actor Critic。
  \item Day5：Lec9 PPO 概念 + 论文一句 ``Isaac+PPO''。
  \item Day6--7：Part V + 论文 Fig.\,4；自己画 Encoder 图。
  \item Day8--10：Part VI；手抄 Eq.\,9；解释 9d。
  \item Day11：读 §IV 消融，对照三条 baseline。
  \item Day12：读 §V 真机段。
  \item Day13：对照你们 \texttt{train\_hop.py}（相同点/不同点）。
  \item Day14：闭卷写「7 句复述」（见下）。
\end{enumerate}

\section*{附录 A：闭卷 7 句（答辩用）}

\begin{enumerate}
  \item 跳跃控制写成 POMDP，因传感器不全且空中久欠驱动。
  \item 用历史 + $\beta$-VAE + 显式速度估计补信息。
  \item 非对称 Actor--Critic：Critic 训练看特权，Actor 可上真机。
  \item 优化器用 PPO，仿真用 Isaac 大规模并行。
  \item 因 3D 并联难仿，改用串联模板训。
  \item 力矩级 Jacobian 映射对齐并联接口与串联动力学；部署去映射。
  \item DR + 地形随机提升 sim-to-real；实验里优于 SLIP 基线。
\end{enumerate}

\section*{附录 B：符号速查}

\begin{tabular}{@{}ll@{}}
$\pi_\theta$ & 策略（Actor）\\
$V_\phi$ & 价值（Critic）\\
$o_t$ / $a_t$ / $r_t$ & 观测 / 动作 / 奖励\\
$\mu_t$ & VAE latent\\
$\mathcal{P},\mathcal{S}$ & Parallel / Serial\\
$J$ & Jacobian\\
$\gamma$ & 折扣\\
\end{tabular}

\section*{附录 C：和你们代码的桥}

\begin{tabular}{@{}p{4.5cm}p{9cm}@{}}
\hline
OMEGA & 你们常见对应物 \\
\hline
Isaac Gym + PPO & Brax PPO + MJX \\
Serial template & （论文路线）本地 \texttt{hopper\_serial.*} \\
并联难仿假设 & 被 MJX \texttt{equality connect} 挑战 \\
History $H=5$ & \texttt{HW\_HIST=5}\\
Phase clock & \texttt{cos/sin(phase)} in \texttt{train\_hop.py}\\
Torque mapping Eq.\,9 & 你们路线通常\emph{不做}；改 DR + 标定 \\
\hline
\end{tabular}

\section*{推荐资源}

\begin{itemize}
  \item CS285 主页与 slides：\url{https://rail.eecs.berkeley.edu/deeprlcourse/}
  \item 中英字幕检索：「UC Berkeley CS285」「Sergey Levine Deep RL」
  \item PPO：Schulman et al.\ arXiv:1707.06347
  \item $\beta$-VAE：Higgins et al.\ ICLR 2017
  \item 论文本地：\texttt{ppopaper}；开源脚注：\texttt{CUHK-BRME/OMEGA}（复现需另取代码）
\end{itemize}

\begin{keyidea}[收束]
\textbf{课件}教你：MDP、策略梯度、AC、PPO、VAE、迁移。\\
\textbf{论文}教你：把它们组装成「可部署的并联腿跳跃」——关键增量在
欠驱动表示 与 serial/torque sim-to-real，而不是发明全新优化器。
\end{keyidea}

\end{document}

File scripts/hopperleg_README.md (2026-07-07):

# Hopper 腿 + 桨 操作手册（PC ↔ Jetson ↔ Pixhawk）

> 这是「不用每次问」的速查手册。按顺序照着做即可。
> 角色：**PC**（你现在敲命令的电脑，有线 `enp44s0` = `192.168.1.2`）跑上层 `run_modee.py`；
> **Jetson** 跑底层驱动 + Pixhawk 桥；**Pixhawk** 出 IMU、驱动 4 合一 ESC 转桨。

---

## 0. 正常开机流程（无故障，按 ①→⑥ 顺序照做）

> 一切正常时就这 6 步。任何一步对不上，去对应的 §排错，修好再继续。

```bash
# ───────────────── 在 PC 上 ─────────────────
# ① 修组播路由（Mihomo 每次重启/重连都会抢，每次开机必做一遍）
sudo ip route replace 224.0.0.0/4 dev enp44s0
ip route get 239.255.76.67 | head -1          # 校验：应显示 dev enp44s0 src 192.168.1.2（不对 → §1）

# ② 找 Jetson 当前有线 IP（DHCP 会变，别死记）。复制下面命令拿到 IP：
#    （完整脚本见 §2；拿到后把 <JETSON_IP> 全部替换成它，最近一次是 192.168.1.100）

# ③ 确认 Jetson 三个底层服务都 active
ssh nvidia@<JETSON_IP> 'systemctl is-active canable.service hopper-driver.service px4-bridge.service'
#    期望输出三行 active。任一不是 → 重启它： ssh nvidia@<JETSON_IP> 'sudo systemctl restart <服务名>'（见 §3）

# ④ 体检：PC 4 秒内能收到各通道（imu/hopper_data 在涨即正常）
#    （脚本见 §6；看到 hopper_imu_lcmt + hopper_data_lcmt 有计数就过）

# ⑤ 开上层（新开一个终端，前台常驻，Ctrl+C 退出时会自动归零所有发送数据）
cd /home/abc/Hopper/hopperHFAcase2026/hopper_controller && python3 run_modee.py
#    终端会刷 mode=<...> foot=[x y z] m。再开一个终端看 spy：
#    cd /home/abc/Hopper/hopperHFAcase2026 && bash hopper_lcm_types/scripts/launch_lcm_spy.sh   （见 §5）

# ───────────────── 在 Jetson 手柄上 ─────────────────
# ⑥ 按 X 进 PD 模式 → 再按 A(开桨) / B(全停) / LB / RB（按键含义见 §7）
```

---

## 1. 网络架构 & 坑

- PC 有线网卡 `enp44s0` = `192.168.1.2/24`，直连 Jetson。
- **坑 1：Mihomo 代理抢组播路由。** 每次 Mihomo 重启/重连，`224.0.0.0/4` 会被改到 `dev Mihomo`，于是 PC 收不到任何 LCM。
  - 修复（PC 上跑，需要密码）：
    ```bash
    sudo ip route replace 224.0.0.0/4 dev enp44s0
    ```
  - 检查当前指向哪：
    ```bash
    ip route get 239.255.76.67 | head -1
    # 正确应是: ... dev enp44s0 src 192.168.1.2 ...
    # 被抢时是:  ... dev Mihomo  src 198.18.0.1 ...
    ```
- **坑 2：Jetson 有线 IP 会变（DHCP）。** 重启后可能从 `.1` 变成 `.100` 等。而且 WiFi 路由器也叫 `192.168.1.1`，所以 SSH 到 `.1` 经常连的是 WiFi 那台、ARP 失败。**别死记 IP，用 §2 的方法现查。**

---

## 2. 找 Jetson 当前有线 IP（万能办法）

即使 SSH/ping 不通，只要还能收到组播，就能从组播包里读出 Jetson 真实源 IP：

```bash
cd /home/abc/Hopper/hopperHFAcase2026/hopper_controller && timeout 6 python3 - <<'PY'
import socket, struct, time
s=socket.socket(socket.AF_INET, socket.SOCK_DGRAM, socket.IPPROTO_UDP)
s.setsockopt(socket.SOL_SOCKET, socket.SO_REUSEADDR, 1)
s.bind(('', 7667))
mreq=struct.pack('4s4s', socket.inet_aton('239.255.76.67'), socket.inet_aton('192.168.1.2'))
s.setsockopt(socket.IPPROTO_IP, socket.IP_ADD_MEMBERSHIP, mreq)
s.settimeout(3); srcs=set(); t0=time.time()
while time.time()-t0<3:
    try: d,a=s.recvfrom(2048); srcs.add(a[0])
    except socket.timeout: break
print('Jetson 组播源 IP:', sorted(srcs) or '(收不到 -> 先修 §1 路由 / 查网线)')
PY
```

拿到 IP 后 SSH：

```bash
ssh nvidia@<JETSON_IP>          # 例: ssh nvidia@192.168.1.100
```

> 收不到任何组播 → 先做 §1 的路由修复；还不行查网线 / Jetson 是否上电。

---

## 3. Jetson 底层服务（systemd）

三个服务，开机相关：

| 服务 | 作用 | 备注 |
|---|---|---|
| `canable.service` | 起 CAN 接口（slcand） | 开机自启 |
| `hopper-driver.service` | AK60 腿电机驱动，发 `hopper_data_lcmt` / `gamepad_lcmt` | `Restart=always`，掉了自动 2s 拉回 |
| `px4-bridge.service` | Pixhawk→`hopper_imu_lcmt`，并把 `motor_pwm_lcmt`→桨 | `Restart=always`，自动找 `/dev/serial/by-id` 稳定串口 |

常用命令（在 Jetson 上，或 `ssh nvidia@<IP> '...'`）：

```bash
# 状态
systemctl is-active canable.service hopper-driver.service px4-bridge.service

# 重启底层腿驱动（最常用：没收到 hopper_data 时）
sudo systemctl restart hopper-driver.service

# 重启桨桥（没收到 hopper_imu / 桨不转时）
sudo systemctl restart px4-bridge.service

# 看日志
sudo journalctl -u hopper-driver.service -n 30 --no-pager
```

> `gamepad_lcmt` **只在你拨动手柄/按键时才发**，静止时看不到是正常的。

---

## 4. PC 上层 `run_modee.py`

**新开一个终端**（前台常驻，看输出，`Ctrl+C` 退出；退出时会自动把所有发送数据归零）：

```bash
cd /home/abc/Hopper/hopperHFAcase2026/hopper_controller
python3 run_modee.py
```

常用参数（按需）：

```bash
python3 run_modee.py --print-hz 5                  # 降打印频率到 5Hz
python3 run_modee.py --pwm-max 1100                 # 正常模式(A键)桨 PWM 上限 1100
python3 run_modee.py --pwm-max 1100 --tau-out-max 1 --thrust-ratio 0.03   # 首次上电更保守
python3 run_modee.py --lcm-url "udpm://239.255.76.67:7667?ttl=255"        # 显式指定 LCM
```

> **`--pwm-max` 只夹「正常模式 / A 键」的桨**（在 `core.step` 里限幅）。
> **LB/RB 切换 loop 里的桨不受 `--pwm-max` 限制**：切换分支直接把 PWM 写成
> `switch_prop_pwm_us = 1600`，不经过限幅。RB 会先把桨斜坡升到该值、腿保持不动，桨到位后腿才动。
> 想改切换桨的值，改 `ModeELCMConfig.switch_prop_pwm_us`，不是 `--pwm-max`。

---

## 5. lcm-spy（GUI，看通道/解码字段）

```bash
cd /home/abc/Hopper/hopperHFAcase2026
bash hopper_lcm_types/scripts/launch_lcm_spy.sh
```

> 该脚本自动 `export LCM_DEFAULT_URL=udpm://239.255.76.67:7667?ttl=255` 并挂上 Java 类型（能解码 q/qd/tau 等字段）。
> 前提：§1 的组播路由已修好，否则 spy 里啥都不出。

---

## 6. 快速体检（命令行，不用 GUI）

PC 上跑，看 4 秒内各通道计数：

```bash
cd /home/abc/Hopper/hopperHFAcase2026/hopper_controller && timeout 6 python3 - <<'PY'
import lcm, time, collections
seen=collections.Counter()
lc=lcm.LCM('udpm://239.255.76.67:7667?ttl=255')
lc.subscribe('.*', lambda ch,data: seen.update([ch]))
t0=time.time()
while time.time()-t0<4.0: lc.handle_timeout(300)
[print(f'  {k}: {v}') for k,v in seen.most_common()] if seen else print('  (空 -> 先修 §1 路由)')
PY
```

**健康基线（大致频率）：**

| 通道 | 来源 | 4s 计数 ≈ | 没有时怎么办 |
|---|---|---|---|
| `hopper_imu_lcmt` | Jetson px4-bridge | ~800 (200Hz) | 重启 `px4-bridge.service` |
| `hopper_data_lcmt` | Jetson hopper-driver | ~4000 (1000Hz) | 重启 `hopper-driver.service` |
| `gamepad_lcmt` | Jetson hopper-driver | 只在动手柄时有 | 拨一下摇杆再看 |
| `hopper_cmd_lcmt` | PC run_modee | ~1700 | 上层没跑 → §4 |
| `motor_pwm_lcmt` | PC run_modee | ~1700 | 上层没跑 → §4 |

---

## 7. 手柄操作（在 Jetson 端的 Xbox 手柄上）

> 前提：上层 `run_modee.py` 在跑，底层 `hopper-driver` active。

| 按键 | 行为 |
|---|---|
| **X** | 进 **PD 模式**。不按则底层只反馈、不施加 `tau_ff`，腿不动（桨走 px4-bridge 不受影响）。 |
| **A** | **桨总开关（control_mode 门控）**。这是唯一能把桨 `control_mode` 切到 ON 的键，px4-bridge 只在 `control_mode==3` 时才真转桨。同时把 PD→PWMPD 用于 SAFE 门控。`pwm_values` 始终是真实指令值。 |
| **B** | **全停**：腿 DAMP + 桨 OFF。 |
| **LB** | **收腿三阶段（不开桨）**：① 1N 恒力收到 -35° → ② 3N 恒力 0.5s → ③ 位置控制到 -30°（kp=12, kd=0.4, 力矩峰值 0.5N）。**整个 LB 过程禁用 SAFE。** |
| **RB** | 同 LB 的三阶段收腿，**额外**：按下 RB **先把桨阶梯斜坡升到 `switch_prop_pwm_us`(=1600)，腿在此期间保持不动(零力矩)**；桨升到 1600 后**腿才开始**阶段 1 收腿。桨在阶段 1/2 + 进阶段 3 的头 1 秒维持 **1600**；**1 秒后交接给「正常 hopper 旋翼参数」(ModeE 的 pwm),不再归零**——从固定 spin-up 平滑过渡到正常桨控制。**但 RB 不会自己切 `control_mode`** —— 桨真转与否由 **A 键**决定:想让 RB 的桨转,必须**先按 A**;A 没开时 `pwm_values` 显示真实值但 `control_mode` 仍 OFF、桨不转。**整个 RB 过程禁用 SAFE。** |

> 注意：阶段 1/2 是力矩控制（不受位置 limit）；阶段 3 位置控制时**也不受 limit**，只有 0.5N 力矩封顶。
> RB 的「先升桨到 1600 再动腿」靠 `_switch_prop_spun_up` 门控:只有当实际(限速后)桨 PWM `prev_pwm_us` 达到 `switch_prop_pwm_us` 才放行腿部阶段 1。
> **LB/RB 切换里的桨也不受上层 `--pwm-max` 限制**——切换分支直接写 `switch_prop_pwm_us`(=1600)，
> 走独立路径，不经过 `core.step` 的 PWM 限幅。`--pwm-max` 只影响正常模式(A 键)的桨。

---

## 8. 故障速查

| 现象 | 原因 | 解决 |
|---|---|---|
| PC 收不到任何 LCM（体检全空） | Mihomo 抢了组播路由 | `sudo ip route replace 224.0.0.0/4 dev enp44s0` |
| SSH `192.168.1.1` 连不上 / `No route to host` | Jetson DHCP 换 IP 了 + WiFi 也占 .1 | §2 现查真实 IP，用新 IP SSH |
| 收得到 `hopper_imu` 但没 `hopper_data` | hopper-driver 掉了 | `sudo systemctl restart hopper-driver.service` |
| 按 RB/LB 腿不动 | 没按 X 进 PD 模式 / 上层没跑 | 按 X；确认 `run_modee.py` 在跑 |
| 桨不转 | px4-bridge 掉了 / 没按 A（普通模式） / Pixhawk 串口变了 | 重启 `px4-bridge.service`（脚本自动找 by-id 串口） |
| 看不到 `gamepad_lcmt` | 手柄静止时本来就不发 | 拨一下摇杆 |
| **桨/姿态"很割裂、卡顿"，`motor_pwm` 数值长时间一模一样不变** | **`hopper_imu` 静默掉线**：FC 的 ATTITUDE 流停了，控制器拿**冻结的旧姿态**算 → 桨输出冻结、偶尔跳。常发生在桥重启后那次 `SET_MESSAGE_INTERVAL` 请求丢了 | 体检看 `hopper_imu_lcmt` 是否=0；现已加**IMU 看门狗**（>1.5s 没 ATTITUDE 自动重发请求，自愈）。仍为 0 就 `sudo systemctl restart px4-bridge.service` |
| 腿方向/角度反 | 关节符号/偏置 | `hopper_hardware.cpp` offset = `+1.4835f`（+85° 全伸） |
| **腿数据在发但 q 冻结 / q 恒为 ≈85°** | **电机 CAN 不回话**（motor_pos=0 → q=offset=85°）。常见于 CANable **bus-off** 锁死（见 §8.2） | 见 §8.2 |
| **桨没信号 / ESC 反复奏乐(开机自检音)** | **跑了多个 `run_modee.py`** 抢同一通道，桨指令开关乱跳 → ESC 反复重启；进程互相打架还会卡死。或 motor_pwm 没到 Jetson（路由/单实例问题） | 见 §8.3 |
| **桨完全无信号 / 不转，连 ESC 自检音都没有** | **飞控 `PWM_AUX_*` 参数被写坏**：AUX1/2/3 的 min/max/disarmed 变成 0 → 飞控恒输出 0us（无脉冲）。常因用 pymavlink 设 **INT32 参数时编码错误**（直接传浮点值而非整数位） | 见 §8.4 |

### §8.4 桨完全无信号 / 不转 —— 飞控 PWM_AUX 参数被写坏（INT32 编码陷阱）

**症状**：桨完全不转，**连 ESC 自检音都没有**（不同于 §8.3 的"反复奏乐"）。`actuator_test` 命令被接受、无报错，但桨纹丝不动。

**根因**：飞控 `pwm_out` 里 AUX1/2/3 的 `min/max/disarmed` 变成 **0** → 飞控给桨**恒输出 0us（无脉冲）** → ESC 收不到任何信号。最隐蔽的来源是**用 pymavlink 设 INT32 参数时编码错误**：

- PX4 的 `PWM_AUX_FUNC* / MIN* / MAX* / DIS*` 都是 **INT32** 参数。
- MAVLink `PARAM_SET` 把值放在一个 4 字节 `param_value`（float）字段里；INT32 参数要求把**整数的字节**塞进去，PX4 收到后按 INT32 `memcpy` 解释。
- 若直接 `param_set_send(name, 1000.0, INT32)`，pymavlink 把 `1000.0` 的**浮点位**（`0x447A0000`）当字节发出 → PX4 当 int 存成 `1148846080`（天文数字）→ mixer 认为超界/无效 → min/max 当 0 → 0us。

**诊断**：
```bash
# 看飞控实际输出范围（关键）；若 AUX 通道 min:0 max:0 → 命中本故障
#   nsh: pwm_out status   →  Channel 0: func:101 ... min:0  max:0   ← 坏
#   正常应是                Channel 0: func:101 ... min:1000 max:2000 value:1000
# 看参数存储的原始整数；param show 把存储 int 直接打印
#   nsh: param show PWM_AUX_MIN1   →  1148846080(坏) / 1000(正常)
```

**修复**：用**正确的 INT32 编码**重写参数（把整数位打包进 float 字段），再 `param save`：
```python
import struct
def set_int(m, name, ival):
    fval = struct.unpack('<f', struct.pack('<i', int(ival)))[0]  # int bits -> float field
    m.mav.param_set_send(m.target_system, m.target_component,
                         name.encode(), fval, mavutil.mavlink.MAV_PARAM_TYPE_INT32)
# PWM_AUX_FUNC1/2/3=101/102/103, MIN/DIS=1000, MAX=2000 ; 之后 nsh: param save
```
修好后 `pwm_out status` 的 AUX 通道应显示 `min:1000 max:2000 value:1000`，ESC 自检音停、桨可被 `actuator_test` 驱动。

### §8.3 桨没信号 / ESC 反复奏乐 —— 只能跑一个 run_modee

**症状**：桨不转或时转时停，ESC 反复播放开机自检音乐；`px4-bridge` 收不到稳定指令。

**根因**：PC 上**同时跑了多个 `run_modee.py`**，它们往同一个 `motor_pwm_lcmt` 抢着发 → `control_mode` 在 ON/OFF 间乱跳 → ESC 反复解除武装/重新初始化（奏乐）。进程互相打架后还可能**卡死**（`kill` 杀不掉，要 `kill -9`），导致干脆不发数据、桨彻底没信号。

**铁律：任何时候只能有一个 `run_modee.py`。**

**排查 / 修复**：
```bash
# PC：看有几个 run_modee（应只有 1 个）
pgrep -af "[r]un_modee"
# 多于 1 个 → 全部杀掉重开一个
pkill -9 -f "[r]un_modee.py"        # 或对每个 PID: kill -9 <PID>
cd /home/abc/Hopper/hopperHFAcase2026/hopper_controller && python3 run_modee.py --pwm-max 1100
```

**验证 Jetson 收到了 PC 的指令**（路由也要先修好，§1）：
```bash
ssh nvidia@<JETSON_IP> 'timeout 5 python3 -c "
import lcm,time,collections; seen=collections.Counter()
lc=lcm.LCM(\"udpm://239.255.76.67:7667?ttl=255\"); lc.subscribe(\".*\", lambda c,d: seen.update([c]))
t0=time.time()
while time.time()-t0<3: lc.handle_timeout(300)
print(dict(seen))"'
# 应看到 hopper_cmd_lcmt 和 motor_pwm_lcmt（来自 PC）。没有 → run_modee 没发/路由没修/启动时路由还被 Mihomo 抢着(重启 run_modee)。
```

> 注意：`run_modee.py` 的组播发送网卡在**启动时**按路由决定。若它在路由被 Mihomo 抢时启动，套接字会绑错网卡，即使之后修了路由也发不到 Jetson —— **先修路由(§1)再启动 run_modee**。

### §8.2 腿"没连接" / q 冻结在 85° —— CAN bus-off 排查

**症状**：`hopper_data_lcmt` 照常 1000Hz 在发，但 `q` 数值**一动不动**，且常常恒为 **≈85°**（=offset，说明 motor_pos 读不到、取了默认 0）。

**诊断**（SSH 到 Jetson）：看 CAN 收包是否在涨——

```bash
ssh nvidia@<JETSON_IP> 'r1=$(cat /sys/class/net/can0/statistics/rx_packets); sleep 1; \
r2=$(cat /sys/class/net/can0/statistics/rx_packets); echo "rx 1s 差 $((r2-r1))  (=0 表示电机零回复)"'
```

- `rx` 差 **=0** 但 `tx` 在涨 → 驱动在喊话、电机不回 → CAN 物理/总线问题。
- 抓帧确认只有发没有回：`candump -n 10 can0`（只看到 ID 001/002/003 的恒定命令帧 = 都是自己发的回显）。

**最常见根因 & 修复（按顺序试）**：
1. **CANable bus-off 锁死**（最常见，尤其改过供电/地之后）：失去共地或总线异常时 CANable 狂发不被 ACK → 进 bus-off，**重启驱动清不掉**，必须**重置 CAN 接口**：
   ```bash
   ssh nvidia@<JETSON_IP> 'sudo systemctl restart canable.service && sleep 2 && sudo systemctl restart hopper-driver.service'
   ```
   重置后 `rx` 立刻开始涨 ≈ `tx`、`q` 变活。
2. **共地**：Jetson 与电机不同电源时，CANable GND 必须和电机/6S 负极实接（万用表量 ≈ 0Ω）。
3. **CANH/CANL 接线松动 / 终端电阻**：动过线后检查 H↔H、L↔L 是否都通，两端 120Ω。
4. **电机没全上电**：确认每个电机控制器指示灯都亮。
| **桨一启动整个就"断连"** | **Jetson 掉电重启（brownout）**：ESC 浪涌电流把供电拽到欠压 → Jetson 复位。重启后 hopper-driver（disabled）不自启，故 `hopper_data` 消失、腿不动；imu 还在因为 px4-bridge 自启。 | 见下方「§8.1 桨 brownout」 |

### §8.1 桨启动导致 Jetson 重启（brownout）— 重要

**诊断**：怀疑掉电重启时，SSH 到 Jetson 看 uptime / last reboot：

```bash
ssh nvidia@<JETSON_IP> 'uptime -p; uptime -s; last reboot | head -3'
```

若 `uptime` 只有几分钟、且 `last reboot` 时间正好是你启动桨的时刻 → 就是 brownout 重启（不是网络/软件问题）。
dmesg 里会看到一整串 USB 设备（手柄 F710、HDMI 音频、蓝牙…）在同一秒重新枚举（冷启动指纹）：

```bash
ssh nvidia@<JETSON_IP> 'sudo dmesg -T | grep -iE "new .* device|input:" | tail -20'
```

**根因**：桨/ESC 与 Jetson 共用供电时，桨启动浪涌把电压拽到 Jetson 欠压阈值以下 → 复位。

**修复（按优先级）**：
1. **电源隔离/扩容**：ESC 与 Jetson 不共用同一路供电，或给 Jetson 单独一路足电流余量的 5V/9V BEC。
2. **加缓冲电容**：Jetson 供电输入端 + ESC 输入端各并大容量电解电容（几百~上千 µF）吸收浪涌。
3. **桨 soft-start**：启动别直接 1200，斜坡缓升（可在 `px4_bridge.py` 给桨加上升斜坡）。

**重启后恢复**：`hopper-driver` 默认 `disabled`（开机不自启，电机安全考虑），brownout 重启后需手动拉起：

```bash
ssh nvidia@<JETSON_IP> 'sudo systemctl restart hopper-driver.service'
```

**桨 soft-start（已实现，降浪涌）**：桨 PWM 硬跳变（1000→1200 瞬间）会一次性拉满 ESC 启动电流 → 拽塌电压。
`_publish_motor_pwm` 现在对**上升**的桨 PWM 限速 `prop_slew_up_us_per_s`（默认 400 us/s，即 1000→1200 约 0.5s 爬完）；
**下降/停止/disarm 立即生效**。想更猛地降浪涌就把这个值调小；设 `1e12` 关掉斜坡。改后重启 `run_modee.py` 生效。

---

## 9. 关键路径备忘

- PC 上层：`/home/abc/Hopper/hopperHFAcase2026/hopper_controller/run_modee.py`
- 控制逻辑：`/home/abc/Hopper/hopperHFAcase2026/hopper_controller/modee/lcm_controller.py`
- spy 脚本：`/home/abc/Hopper/hopperHFAcase2026/hopper_lcm_types/scripts/launch_lcm_spy.sh`
- Jetson 底层：`/home/nvidia/Hopper_srbRL/build/hopper_driver`
- Jetson 桨桥：`/home/nvidia/Hopper_srbRL/pixhawk/px4_bridge.py`
- systemd unit：`/etc/systemd/system/{canable,hopper-driver,px4-bridge}.service`（在 Jetson 上）
- LCM URL：`udpm://239.255.76.67:7667?ttl=255`

---

## 10. 桨配置（Y 120° 三旋翼，2026-06 最终标定）

**实机标定**（2026-06-25）：控制器/机体系是 **FRD（x 前 / y 右 / z 下）**。电机1 在 **−Y**；电机2=**右前**；电机3=**右后**。

控制器帧（FRD）下的几何：

| 电机 (PWM 通道) | 位置 | 方位 | 几何角 |
|---|---|---|---|
| 电机 1（pwm[1]） | (0, −Y) | **−Y 侧** | - |
| 电机 2（pwm[2]） | (+X, +Y) | **右前** | - |
| 电机 3（pwm[3]） | (−X, +Y) | **右后** | - |

> 分配是 `core.py` 里用 `prop_positions_b` 现算的 **r × ẑ 力矩映射**（无硬编码矩阵；不建模偏航 yaw）。
> 映射 `prop_pwm_idx_per_arm`：arm i → 电机 i+1。
>
> **上电前手扶验证**：桨低权限，根据右侧三桨几何检查 `r×ẑ` 力矩方向；如果 roll/pitch 反向，优先检查 `prop_positions_b`，不要再换 PWM 通道。

### 改桨转向（正转/反转）

**软件 PWM 改不了转向**，只能改转速。转向要在 **ESC（DShot）** 层改：

| 方法 | 说明 |
|---|---|
| **PX4 NSH（推荐）** | 停 `px4-bridge` 后：`dshot reverse -m 1` + `dshot save -m 1`（电机2 把 `1` 换成 `2`）。脚本：`hopperMOBILEmanipulation/pixhawk/fc_reverse_motors.py DEV --motors 1,2` |
| **QGroundControl** | Actuators → Testing → **Set Spin Direction**（DShot ESC） |
| **换线** | ESC 上任意两根电机线对调（定距桨常用办法） |

> **注意**：定距桨反转后 **升力仍朝上**，只是反扭矩（偏航 yaw）反了。ModeE **不建模**桨 yaw 反扭矩，所以改转向**不会**修 roll/pitch 姿态分配问题；那是 `prop_positions_b` 几何的事。

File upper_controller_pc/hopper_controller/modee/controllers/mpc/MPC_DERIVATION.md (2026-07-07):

# MPC 数学推导文档

## 1. SRB (Single Rigid Body) 动力学模型

### 1.1 状态变量

```
x = [p(3), v(3), rpy(3), omega(3), yaw_ref(1)]  (13维)
```

- `p`: COM 位置 (world frame, +Z up)
- `v`: COM 速度 (world frame)
- `rpy`: 姿态角 (roll, pitch, yaw, 在 yaw 线性化后的 heading frame)
- `omega`: 角速度 (world frame)
- `yaw_ref`: 参考 yaw（用于线性化）

### 1.2 控制变量

```
u = [f_foot_w(3), t_rotors(3)]  (6维)
```

- `f_foot_w`: 足端 GRF (ground reaction force, world frame, +Z up)
- `t_rotors`: 三个螺旋桨推力 (每个 arm 一个，标量)

### 1.3 动力学方程（离散化，Euler 积分）

#### 位置更新
```
p[k+1] = p[k] + v[k] * dt + 0.5 * a[k] * dt^2
```

#### 速度更新（牛顿第二定律）
```
v[k+1] = v[k] + a[k] * dt

其中：
a[k] = (1/m) * (f_foot_w[k] + z_w * sum(t_rotors[k])) + g_world
```

- `m`: 机器人质量
- `z_w`: body +Z 轴在 world frame 的方向（从当前姿态得到，horizon 内视为常数）
- `g_world = [0, 0, -g]`: 重力加速度（world frame，+Z up）

#### 姿态更新（小角度线性化，yaw 固定）
```
rpy[k+1] = rpy[k] + Rz(-yaw_ref) * omega[k] * dt
```

其中 `Rz(-yaw_ref)` 是 yaw 旋转矩阵的逆，用于将 world frame 的角速度转换到 heading frame。

#### 角速度更新（欧拉方程）
```
omega[k+1] = omega[k] + I_w_inv * tau[k] * dt
```

其中：
- `I_w = Rz(yaw_ref) * I_body * Rz(yaw_ref)^T`: body 惯性矩阵在 world frame 的表示
- `tau[k]`: 总力矩（world frame）

力矩来源：
1. **GRF 力矩**：`tau_grf = r_foot_w × f_foot_w`
   - `r_foot_w`: 足端位置相对于 COM（world frame）

2. **螺旋桨力矩**：`tau_props = sum_i (r_i_w × (z_w * t_i))`
   - `r_i_w`: 第 i 个螺旋桨位置相对于 COM（world frame）
   - 每个螺旋桨推力沿 body +Z 方向，在 world frame 为 `z_w * t_i`

#### yaw_ref 更新
```
yaw_ref[k+1] = yaw_ref[k] + yaw_rate_ref * dt
```

### 1.4 线性化后的状态空间形式

将所有更新写成矩阵形式：

```
x[k+1] = A * x[k] + B * u[k] + b
```

其中：
- `A`: (13×13) 状态转移矩阵
- `B`: (13×6) 控制输入矩阵
- `b`: (13×1) 常数项（主要是重力）

**A 矩阵结构**：
```
A = [I3    dt*I3   0      0       0    ]  (位置)
    [0     I3      0      0       0    ]  (速度)
    [0     0       I3    dt*Rz_m 0    ]  (姿态)
    [0     0       0     I3      0    ]  (角速度)
    [0     0       0     0       1    ]  (yaw_ref)
```

**B 矩阵结构**：
```
B = [0.5*dt^2/m * I3    0.5*dt^2/m * Z]  (位置)
    [dt/m * I3          dt/m * Z      ]  (速度)
    [0                  0              ]  (姿态)
    [dt * I_w_inv * S   dt * I_w_inv * C] (角速度)
    [0                  0              ]  (yaw_ref)
```

其中：
- `Z = [z_w, z_w, z_w]`: (3×3) 每列都是 `z_w`
- `S = skew(r_foot_w)`: (3×3) GRF 力矩的叉乘矩阵
- `C`: (3×3) 螺旋桨力矩的系数矩阵，`C[:,i] = cross(r_i_w, z_w)`

**b 向量**：
```
b = [0.5*dt^2 * g_world, dt * g_world, 0, 0, 0, dt * yaw_rate_ref]^T
```

---

## 2. Condensed QP 形式推导

### 2.1 Full-space MPC 问题

原始 MPC 问题（full-space）：

```
minimize: sum_{k=0}^{N-1} ||x[k+1] - x_ref[k+1]||_W^2 + ||u[k]||_K^2

subject to:
  x[k+1] = A * x[k] + B * u[k] + b  (k=0..N-1)
  u[k] in U_k  (控制约束：摩擦锥、推力上下限等)
```

其中：
- `W`: 状态跟踪权重（对角矩阵）
- `K`: 控制正则化权重（对角矩阵）
- `U_k`: 第 k 步的控制约束集

### 2.2 状态消除（Condensing）

将状态序列用初始状态和控制序列表示：

```
X = [x[1], x[2], ..., x[N]]^T  (N*nx 维)
U = [u[0], u[1], ..., u[N-1]]^T  (N*nu 维)
```

通过递归代入动力学方程，得到：

```
X = A_qp * x[0] + B_qp * U + xbar
```

**推导过程**：

1. **A_qp 矩阵**（状态传播）：
   ```
   x[1] = A * x[0] + B * u[0] + b
   x[2] = A * x[1] + B * u[1] + b
        = A^2 * x[0] + A * B * u[0] + B * u[1] + (A*b + b)
   ...
   x[k] = A^k * x[0] + sum_{j=0}^{k-1} A^{k-1-j} * B * u[j] + (A^{k-1}*b + ... + b)
   ```

   因此：
   ```
   A_qp = [A; A^2; ...; A^N]  (N*nx × nx)
   ```

2. **B_qp 矩阵**（控制影响）：
   ```
   B_qp = [B,     0,     0,   ..., 0    ]
          [A*B,   B,     0,   ..., 0    ]
          [A^2*B, A*B,   B,   ..., 0    ]
          ...
          [A^{N-1}*B, ..., A*B, B]  (N*nx × N*nu)
   ```

   这是一个下三角块矩阵，因为 `u[j]` 只影响 `x[j+1]` 及之后的状态。

3. **xbar 向量**（常数项传播）：
   ```
   xbar = [b; A*b+b; A^2*b+A*b+b; ...]  (N*nx 维)
   ```

### 2.3 Condensed QP 问题

将状态消除后，问题变成只优化控制序列：

```
minimize: (1/2) * U^T * H * U + g^T * U

subject to:
  lU <= U <= uU  (控制上下限)
  A_fr * U <= b_fr  (摩擦锥约束)
  A_sum * U in [l_sum, u_sum]  (总推力约束)
  (可选) A_tau * U in [l_tau, u_tau]  (关节力矩约束)
  (可选) A_rp * (A_qp*x0 + B_qp*U + xbar) in [l_rp, u_rp]  (姿态约束)
```

**Hessian 矩阵 H**：
```
H = 2 * (B_qp^T * W_block * B_qp + K_block)
```

其中：
- `W_block = kron(I_N, W)`: 块对角状态权重矩阵
- `K_block = kron(I_N, K)`: 块对角控制权重矩阵

**梯度向量 g**：
```
g = 2 * B_qp^T * W_block * (A_qp * x[0] + xbar - X_ref)
```

其中 `X_ref` 是参考状态序列堆叠。

---

## 3. 约束处理

### 3.1 摩擦锥约束（Friction Pyramid）

真实摩擦锥是圆锥：
```
|f_xy| <= mu * fz
```

为了在 QP 中表示，用**内接菱形（diamond）**近似：
```
|fx| + |fy| <= mu * fz
```

这可以写成 4 个线性约束：
```
+fx +fy - mu*fz <= 0
+fx -fy - mu*fz <= 0
-fx +fy - mu*fz <= 0
-fx -fy - mu*fz <= 0
```

### 3.2 总推力约束

```
sum(t_rotors) in [thrust_sum_min, thrust_sum_max]
```

这可以写成：
```
A_sum * U in [l_sum, u_sum]
```

其中 `A_sum` 的每一行在对应步的推力变量位置为 1，其他为 0。

### 3.3 关节力矩约束（可选）

如果提供 `A_tau_f`（雅可比转置映射），可以约束：
```
|A_tau_f * f_foot_w| <= tau_cmd_max
```

这确保 MPC 生成的 GRF 可以通过腿关节实现。

---

## 4. 代码实现关键点

### 4.1 `_build_dynamics()` 函数

构建 `A, B, b` 矩阵，对应上述数学推导。

### 4.2 `_condense()` 函数

实现状态消除，计算 `A_qp, B_qp, xbar`。

### 4.3 `solve()` 函数

1. 调用 `_build_dynamics()` 和 `_condense()` 得到 condensed 形式
2. 构建 QP 的 `H, g`（Hessian 和梯度）
3. 构建约束矩阵和上下限
4. 调用 OSQP 求解器求解
5. 返回第一步的控制 `u[0]`（MPC 只执行第一步，然后重新规划）

---

## 5. 为什么用 Condensed 形式？

**优点**：
- 变量数从 `(N*nx + N*nu)` 降到 `N*nu`（状态被消除）
- 约束数也减少（状态约束变成控制约束）
- 求解更快

**缺点**：
- `B_qp` 矩阵是稠密的（下三角块），内存占用 `O(N^2)`
- 当 `r_foot_w` 变化时，需要重新计算 `B_qp`（代码支持 LTV 版本 `_condense_ltv()`）

---

## 6. 与 Hopper4 的区别

- **Hopper4**: 只用 GRF，没有螺旋桨推力作为决策变量
- **ModeE**: GRF + 3 个螺旋桨推力，形成 "wrench MPC"
- 这允许 MPC 同时优化接触力和推力分配，实现更好的姿态/速度权衡

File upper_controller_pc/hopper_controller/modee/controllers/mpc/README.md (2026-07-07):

# MIT-style Model Predictive Control

基于MIT Cheetah论文的MPC控制器实现。

## 架构

```
┌─────────────────────────────────────────────────┐
│                   MPC Controller                │
├─────────────────────────────────────────────────┤
│                                                 │
│  状态: x = [px, py, pz, vx, vy, vz,            │
│             roll, pitch, ωx, ωy]   (10D)       │
│                                                 │
│  输入: u = [fx, fy, fz, T]         (4D)        │
│         接触力(世界系) + 总推力                 │
│                                                 │
├─────────────────────────────────────────────────┤
│                                                 │
│  优化问题:                                      │
│  min  Σ ||x_k - x_ref||²_Q + ||u_k||²_R        │
│                                                 │
│  s.t. x_{k+1} = A_k x_k + B_k u_k + c_k        │
│       |f_xy| ≤ μ·f_z      (摩擦锥)             │
│       f_z ∈ [f_min, f_max] (接触时)            │
│       f = 0               (飞行时)              │
│       T ∈ [T_min, T_max]  (推力限制)           │
│                                                 │
└─────────────────────────────────────────────────┘
```

## 文件结构

```
mpc/
├── __init__.py          # 模块导出
├── mit_mpc.py           # MPC控制器 (QP求解)
├── srb_dynamics.py      # 单刚体动力学模型
└── README.md            # 本文档
```

## 使用方法

### 基本使用

```python
from controllers.mpc import MITMPC, MITMPCConfig

# 创建MPC
cfg = MITMPCConfig(
    dt=0.02,       # 20ms 时间步
    N=15,          # 15步预测 (0.3s)
    mu=1.0,        # 摩擦系数
    fz_max=200.0,  # 最大接触力
    T_max=15.0,    # 最大推力
)
mpc = MITMPC(cfg)

# 当前状态
x0 = np.array([
    0, 0, 0.5,     # 位置 [m]
    0, 0, 0,       # 速度 [m/s]
    0, 0,          # roll, pitch [rad]
    0, 0,          # 角速度 [rad/s]
])

# 参考状态
x_ref = np.array([0, 0, 0.6, 0.3, 0, 0, 0, 0, 0, 0])

# 足端位置 (相对质心, 世界系)
r_foot = np.array([0, 0, -0.5])

# 接触调度 (1=支撑, 0=飞行)
contact_schedule = np.array([1]*5 + [0]*10)

# 求解
sol = mpc.solve(x0, x_ref, r_foot, contact_schedule)

# 获取第一个输入
f_contact = mpc.get_contact_force(sol)  # [fx, fy, fz]
thrust = mpc.get_thrust(sol)            # T
```

### 权重调节

```python
cfg = MITMPCConfig(
    # 状态跟踪权重
    w_pz=50.0,      # 高度跟踪
    w_vx=10.0,      # 前向速度
    w_vy=10.0,      # 侧向速度
    w_vz=20.0,      # 垂直速度
    w_roll=100.0,   # 横滚姿态
    w_pitch=100.0,  # 俯仰姿态
    
    # 输入正则化
    w_f=1e-4,       # 接触力
    w_T=1e-3,       # 推力
)
```

## 动力学模型

### 单刚体 (SRB) 假设

1. **小角度近似**: roll/pitch 接近零
2. **忽略yaw**: 三旋翼无法主动控制yaw
3. **点接触**: 足端单点接触
4. **推力沿体轴**: 总推力沿body z轴

### 状态方程

```
位置: dp/dt = v
速度: dv/dt = (f + T·z_body) / m + g
姿态: dθ/dt = ω
角速度: dω/dt = I⁻¹ · (r × f)
```

## 参考文献

1. MIT Cheetah 3: "Highly Dynamic Quadruped Locomotion via Whole-Body Impulse Control"
2. Convex MPC: "Dynamic Locomotion in the MIT Cheetah 3 Through Convex Model-Predictive Control"
3. Mini Cheetah: "MIT Cheetah 3: Design and Control of a Robust, Dynamic Quadruped Robot"

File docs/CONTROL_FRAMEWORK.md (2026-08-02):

# Hopper 跳跃控制框架（Mode1 + 三旋翼）

> 对应代码：`upper_controller_pc/hopper_controller/modee/core.py`
> 基座：2026-07-20 `2aa050e` 的 Mode1 控制器（虚拟弹簧腿 + hip-torque SRB 姿态 + Raibert 落点），
> 2026-08-01 重建，加入：解耦三旋翼分配器、桨能量补充（PUSH→apex）、PogoX 式飞行速度收敛。
> 2026-08-01 (v2)：stance 能量律默认切换为 **NRC 连续律**（§2b，Lo/Chu/Au ACC 2020），
> Mode1 两段弹簧保留为 `stance_energy_law = "mode1"` 可选回退。

---

## 0. 设计原则

- **优先级**：① 跳跃高度/能量 ② 姿态稳定 ③ 速度收敛。饱和时按此顺序让路（分配器的
  lexicographic `s` 缩放）。
- **正交通道**：腿轴向力（能量）、腿侧向力/hip torque（stance 姿态）、桨 collective（Fz 能量）、
  桨差分（姿态力矩）四个通道物理上互不污染。
- **不要硬切**：所有过渡都是物理量驱动的连续函数——PUSH 弹簧 blend、桨补能的 vz 淡出、
  倾斜的斜坡限速、落地回平的连续预算。唯一的离散事件是物理接触（TD/LO）本身。
- **耦合走物理测量**：腿和桨两个能量源不在 tick 内解代数环，而是通过**apex 回程映射**
  （每跳实测顶点高度 → `E_loss` 自适应）逐跳耦合收敛。

---

## 1. 相位机（事件驱动，无时间表）

```
TD (q_shift ≤ -2cm) ──► COMPRESSION ──► PUSH latch (vz_f 过零去抖) ──► LO (腿伸展阈值)
      ▲                                                                    │
      └───────── descent ◄── apex (vz_up=0) ◄── ascent ◄──────────────────┘
```

- TD/LO 由腿长/关节位移的物理阈值触发，带最小相位时间去抖。
- PUSH latch：世界系竖直速度（LPF 后）过零 + 连续 tick 确认 —— 即"到底了"。
- apex 不是事件，是 `vz_up = 0` 这个物理点，所有随 apex 消失的量都用 vz 连续淡出。

## 2. 腿：能量注入（Hopper4 两段弹簧）

**COMPRESSION**（落地承接）：固定增益世界高度阻抗
\[ f_z = k_z (h_{des} - h_{com}) - b_z v_z, \quad h_{des} = l_0 + h_{hop} \]

**PUSH**（一次性重解弹簧，从底部释放）：在 latch 时刻解
\[ \tfrac12 k_{push} x_0^2 = \underbrace{\tfrac12 m v_{to}^2}_{顶点动能} + \underbrace{m g_{st} x_0}_{提升} + \underbrace{E_{loss}}_{逐跳学习}, \quad v_{to} = \sqrt{2 g_{up} h_{tgt}} \]

- \(x_0 = l_0 - h_{com}\)：底部的世界系高度亏欠（不是腿长压缩量）。
- 力从压缩力连续 blend 过去（`stance_push_blend_tau_s`），不跳变。
- **腿力预算**：\(k_{push} \le f_{z,cap}/x_0\)。封顶后腿存不满 \(E_{need}\) → 差额交给桨（§3）。
- **apex 回程映射**：每跳飞行时间实测顶点高度，误差以增益 γ 折进 \(E_{loss}\)
  （Koditschek–Buehler 离散能量调节，1-D 收缩）。这是腿/桨双能量源的耦合闭环。
- RB 手柄大跳：下一次 PUSH 用 \(h_{tgt} \times\) `big_jump_height_gain`，一跳后自动恢复。

## 2b. NRC 连续能量律（新默认，`stance_energy_law = "nrc"`）

> 来源：Lo, Chu, Au, *A Norm-Regulation-Based Limit Cycle Control of Vertical Hoppers*, ACC 2020。
> 动机：Mode1 的 PUSH latch + 一次性重解弹簧在 latch 时刻产生 \(f_z\) 跳变（log 里 10 ms 内
> 130→430 N），是 tau 抽搐的主因之一。NRC 用**一条连续力律覆盖整个 stance**，能量误差在
> **stance 内部**单调收敛，不需要 latch、不需要 blend、不需要逐跳的 \(E_{loss}\) 映射。

**归一化相平面**（世界系竖直、向上为正）：
\[ \omega = \sqrt{k/m}, \qquad x_1 = (h_{com} - l_0) + \frac{m g_{st}}{k}, \qquad x_2 = \frac{v_z}{\omega} \]

极限环是相平面上的圆 \(\|x\| = r^\*\)。**高度耦合**就在目标半径里：
\[ v_{to} = \sqrt{2 g_{up} h_{hop}}, \qquad r^\* = \Big\| \big( \tfrac{m g_{st}}{k},\; \tfrac{v_{to}}{\omega} \big) \Big\| \]
（\(g_{st}, g_{up}\) 是桨怠速 collective 折算后的有效重力——桨的存在直接改写能量目标。）

**控制律**（论文 NRC-2 平滑版）：
\[ F_{pump} = -2 m k_R \omega\, x_2 (\|x\| - r^\*), \qquad f_z = \mathrm{clip}\big(k(l_0-h_{com}) - b_z v_z + F_{pump},\; 0,\; f_{z,cap}\big) \]

- \(\tfrac{d}{dt}\|x\| = -2 k_R x_2^2 (1 - r^\*/\|x\|)\)：半径误差在 stance 内单调衰减 →
  **一个 stance 内收敛**（1D 仿真：静止零能量起步，第一跳即 6.84 cm / 目标 7 cm，之后死平）。
- \(x_2=0\)（底部）时 \(F_{pump}=0\)：**底部无力尖峰**，能量摊在整个行程注入 → 无 chatter。
- 收敛后 \(F_{pump} \to 0\)，剩纯弹簧——极限环上控制器"消失"。
- TD 时刻若上一跳能量正确则 \(\|x\| \approx r^\*\) → 力从 0 连续起步，TD 也无跳变。
- **桨融合（stance）**：每 tick 按**腿的真实能力** `nrc_leg_fz_max` 切分，残差进桨 collective：
  \[ f_{leg} = \mathrm{clip}(f_{des},\,0,\,F_{leg}^{max}), \qquad F_{prop} = \mathrm{clip}(f_{des} - F_{leg}^{max},\, 0,\, \rho_{max} m g) \]
  两者相加恰好复现 NRC 需求（直到双双饱和），连续量、纯 Fz 通道，桨不解除时腿被要求全额。
  > 2026-08-02 修正：这里原先对着 `stance_fz_max`（500 N 硬件钳位）取残差，而 NRC 需求
  > p95 只有 259 N，导致 **stance 内桨永远不介入**（063655 log：桨补能 41 tick 全在空中）。
  > 分割点必须是**髋力矩能真正给出的轴向力**（此几何下约 15 N/N·m，10 N·m 上限 → 约 150 N），
  > 否则腿在命令 430 N、限幅器把它缩到 1/3、桨还在怠速——就是"腿无力"。改 `tau_out_max`
  > 时要同步改这个值。
- **桨融合（flight 上升段）**：对**当前弹道**的 apex 预测误差做纯反馈：
  \[ h_{pred} = h + \frac{v_z^2}{2g}, \qquad F = \mathrm{clip}\Big(k_h\, m g\, \frac{(l_0 + h_{hop}) - h_{pred}}{h_{hop}},\, 0,\, \rho_{max} m g\Big) \cdot \mathrm{clip}\big(\tfrac{v_z}{v_{fade}}, 0, 1\big) \]
  弧线已够高 → 力为 0；不够 → 连续泵，apex 处淡出归零。自限幅，无锁存。
- 大跳：TD 时消费 RB 请求，整个 stance 以 \(h_{hop} \times\) gain 为目标，LO 恢复。

**调参表（就这几个）**：

| 参数 | 默认 | 物理含义 | 怎么调 |
|---|---|---|---|
| `hop_height_m` | 0.07 | apex 目标（唯一高度源头） | 想跳多高改这个 |
| `nrc_k_n_m` | 1400 | 虚拟弹簧刚度 | 触底太深/stance 太长 → 调大；落地太硬 → 调小（深度≈\(v_{td}\sqrt{m/k}\)，时长≈\(\pi\sqrt{m/k}\)≈0.22 s） |
| `nrc_kR` | 400 | 能量泵增益 | 高度收敛慢/跳不到 → 调大；中段力峰太大 → 调小 |
| `nrc_bz` | 8 | 小阻尼（防振动） | 腿振铃 → 调大一点；它耗的能 kR 会自动补回 |
| `nrc_leg_fz_max` | 160 | 腿/桨分界（腿的真实轴向力能力，N） | 约等于 `tau_out_max` × 15；调小 = 更早让桨接手 |
| `prop_energy_max_ratio` | 0.35 | 桨补能上限（×mg） | 桨介入太猛 → 调小 |
| `prop_height_kh` | 1.0 | 飞行段 apex 误差增益 | 0 = 纯腿；跳不够高且腿已饱和 → 调大 |
| `prop_energy_apex_fade_vz` | 0.30 | apex 前淡出窗口 (m/s) | 一般不动 |

日志新列：`nrc_r` / `nrc_r_star`（相平面半径 vs 目标，二者贴合 = 能量在环上）、`nrc_f_des`
（分割前的总需求）、`prop_energy_fz`（stance = 腿残差进桨的力；flight = apex 误差反馈力）。
检查分割是否正常：stance 内应有 `f_ref_w2 + prop_energy_fz ≈ nrc_f_des`。

## 3. 桨：能量补充（PUSH → apex，解耦的 Fz 通道）—— Mode1 回退路径

腿被力预算封顶时的能量缺口：
\[ E_{def} = \max\!\big(0,\; E_{need} - \tfrac12 k_{boost} x_0^2\big) \]

桨没有行程限制，力作用在 **PUSH 行程 + 整个上升段**：
\[ F_{prop} = \min\!\Big( \frac{E_{def}}{x_0 + h_{tgt}},\; \rho_{max}\, m g \Big) \]

- **stance PUSH**：collective = 怠速基座 + \(F_{prop}\)。
- **flight 上升**：继续出力，用物理变量 vz 连续淡出：
  \[ F(t) = F_{prop} \cdot \mathrm{clip}\!\big(v_z^{up} / v_{fade},\, 0,\, 1\big) \]
  \(v_z^{up}=0\)（apex）时力恰好归零——滚降跟着剩余上升走，无开关无定时器。
- **下降段**：回到怠速，不加 Fz。
- 只进分配器的 **collective 通道**（纯 collective 零力矩），姿态差分完全不受影响。
- 上升段的额外做功如造成顶点超调，由 §2 的回程映射逐跳吸收。

## 4. 姿态：SO(3) 几何 PD，双执行器分工

误差（Lee et al. CDC'10）：\(e_R = \tfrac12 (R_{des}^T R - R^T R_{des})^\vee\)，参考保测量 yaw。

- **stance**：\(\tau_b = -k_R e_R - k_W \omega\)（可选转速观测器），投影掉点足腿轴不可发力方向，
  由 SRB 闭式解转成世界系接触力：固定 \(f_z\) 竖直支撑，反解水平 \(f_{xy}\)，摩擦锥按比例缩
  （方向保持）。桨差分只补**腿分配后剩下的残差力矩**（HFA Eq.12）。
- **flight**：桨差分是唯一姿态执行器，同一个 \(k_R/k_W\) PD 跟踪 §6 的倾斜参考。
  腿此时做 Raibert 摆腿（§5），互不争抢。

## 5. 水平速度收敛（两层结构，与高度旋钮同步；2026-08-02 重构）

**问题定义**：镇定水平速度误差 \(e_v = \hat v_{xy} - v_{des}\)，同时 (a) 不侵占高度
通道的能量预算，(b) 落地前身体回平，(c) 所有过渡连续。

**估计（两层共享同一个 \(\hat v\)，不锁存）**：
- stance：着地足里程计 \(v = R(-\dot p_f^b - 0.1\,\omega\times p_f^b)\)（世界系），
  推进段末 N 拍均值作 LO 初值；
- flight：从 LO 初值起 **IMU 世界系比力逐 tick 外推** \(v \mathrel{+}= (R a_b + g)\,dt\)
  ——桨的刹车会真实反映在速度里，两层消费同一个活的估计（三旋翼串级的标准假设，
  Salazar-Cruz CEP'09）。

### 5a. Layer 1 —— Raibert 返回映射落点（hop-to-hop，主收敛）

教科书双项形式（Raibert 1986），世界系 FRD：
\[ p_{xy} = \underbrace{\tfrac{T_{st}}{2}\,\hat v_{xy}}_{\text{中性点}}
   + \underbrace{k_{step}\,(\hat v_{xy} - v_{des})}_{\text{反馈}},\qquad
   p_z = \sqrt{l_0^2 - \|p_{xy}\|^2},\qquad p_b = R^T p_w \]

- **中性点与高度通道同步**：stance 是 `nrc_k_n_m` 虚拟弹簧的半周期，
  \(\tfrac{T_{st}}{2} = \tfrac{\pi}{2}\sqrt{m/k}\) **实时从刚度旋钮算出**
  （k=1800 → 0.096 s）。改高度通道的 k，落点法则自动重新定时——以前这一项
  被埋在一个手调增益里。
- **反馈增益** \(k_{step}\) = `flight_kv`（现 0.08）：线性化返回映射的
  deadbeat 值约为 \(T_{st}/2\)，故有效范围 0.03（温和）～0.10（近 deadbeat）。
- \(v_{des}\) 以**正确的 Raibert 符号**进入（要向前走 → 脚落在中性点之后）；
  旧的 `+flight_kr` 前馈退役。
- 摆腿是足空间笛卡尔 PD（侧向力正交于腿轴 + 轴向弹簧），限步长
  `flight_stepper_lim_m`。

### 5b. Layer 2 —— 三旋翼倾斜（within-flight，连续阻尼）

外环每 tick 闭在活的速度上（Lee CDC'10 / PogoX ICRA'24）：
\[ a_{des} = k_v^{tilt} (v_{des} - \hat v(t)) \;\rightarrow\;
   z_b^{des} \propto \big[-m\,a_{des,xy},\; F_z\big] \;\rightarrow\; R_{des}(\text{保 yaw}) \]

**方向来自速度环、幅值来自高度通道**：交付的侧向力是 \(f_{xy} = F_z\tan\theta\)，
其中 \(F_z\) 是高度通道**当刻**的 collective（怠速 + §2b/§3 补能 + kh 反馈）。
高度出多少力，速度环就借多少来转向——不为速度多叠 PWM，通道在意图上正交：

| 飞行段 | \(F_z\) 来源 | 18° 倾角的侧向力 |
|---|---|---|
| 上升 | 怠速 + 能量补充（10–40 N） | 3–13 N（真刹车） |
| 下降（旧） | 怠速 0.68 N | 0.2 N（≈无） |
| 下降（新） | 怠速 + **下降刹车授权** | 最多 ~2.3 N |

**下降刹车授权**（`prop_descent_brake_*`，修旧结构的硬伤）：
\[ \Delta F_z = \rho_{brake}\, mg \cdot
   \mathrm{clip}\!\big(\tfrac{\|e_v\|}{e_{ref}},0,1\big) \cdot
   \mathrm{clip}\!\big(\tfrac{t_{td}-t_{settle}}{t_{settle}},0,1\big) \]
误差门控（收敛了就归零）+ 与倾斜预算同一个 \(t_{td}\) 时钟淡出（落地前既回平又
回怠速）。竖直方向的少量能量由逐跳 apex trim（§2b）跨跳吸收。

**落地预算（PogoX，保留）**：倾角 θ 需要 θ/slew 秒还清 + settle 余量，
\[ \theta_{budget} = \mathrm{slew}\cdot\max(0,\; t_{td} - t_{settle}) \]
其中 \(t_{td}\) 由弹道预测——apex 目标是 `hop_height_m`×`nrc_h_trim`，
**高度旋钮改了，倾斜授权窗口自动跟着变**。预算以 slew 速率收零，斜坡参考精确
跟得上，无 on/off 门。倾斜参考在角度空间斜坡限速，R_des 全程连续。

### 5c. 分工与饱和字典序

- Layer 1 在触地瞬间以冲量方式消化误差（离散、大权限）；Layer 2 在飞行中连续
  消耗误差并把 Layer 1 的落点残差在下一次触地前压小（连续、小权限）。
  两层都指向同一个 \(v_{des}\)，靠共享 \(\hat v\) 自然协同，无仲裁逻辑。
- 桨的饱和字典序：**collective（高度）> 差分回平（稳定）> 倾斜（速度）**——
  倾斜只改姿态参考的方向，差分被 `prop_att_thrust_max_each_n` 硬顶，
  collective 永远不被速度环触碰。

## 6. 分配器：怠速基座差分混合（有界抬升）

每桨命令 \(t_i = T/3 + c + s\,\Delta_i\)：

- **[Fz] collective** \(T\)：全周期 = PWM 1100 怠速（每桨 0.225 N ≈ 0.0103 mg 合计），
  唯一计划内加成是 §3 的能量补充。
- **[τ] 差分** \(\Delta\)：\(M_{[:2]}\Delta = \tau_{xy}\) 最小范数解 + 零和投影（纯力矩）。
  怠速基座下行余量只有 ~0.1 N，所以按三旋翼低怠速惯例：最低桨压在地板 \(t_{min}\)，
  需要力矩的桨从基座**往上抬**（最小抬升 \(c\)），每桨硬顶
  \(t_{ceil} = T/3 + \) `prop_att_thrust_max_each_n`（3 N ≈ PWM 1380）——**不叠 PWM**。
- **饱和**：单标量 \(s\in[0,1]\) 缩整个差分（力矩方向精确），遥测列 `prop_att_scale`
  记录实际交付比例（<1 说明姿态需求被削）。

## 7. "无硬切"清单

| 过渡 | 连续机制 |
|---|---|
| COMP → PUSH 力 | `stance_push_blend_tau_s` 一阶 blend |
| 桨补能 → apex 结束 | \(F \propto \mathrm{clip}(v_z^{up}/v_{fade})\)，vz=0 时自然归零 |
| 倾斜建立/撤销 | 角度空间斜坡限速 |
| 落地前回平 | 连续预算 \(\theta_{budget}(t_{td})\)，以 slew 速率收零 |
| 低 collective 下的速度环 | 侧向力 \(f_z\tan\theta\) 随 \(f_z\to0\) 物理淡出，无门 |
| 姿态饱和 | 单标量 s 缩放，方向不变 |
| 反转地板进出 | 可行性触发 + 迟滞（"auto"），非角度阈值 |

## 8. 调参表

| 参数 | 现值 | 作用 |
|---|---|---|
| `hop_height_m` | 0.07 | 顶点高度目标（能量源头） |
| `stance_kp_z / kd_z` | 1400 / 10 | 落地承接阻抗 |
| `stance_push_blend_tau_s` | 0.01 | PUSH 力上升时间（抖→调大） |
| `mode1_apex_adapt_gamma` | 0.4 | 逐跳能量学习速率 |
| `prop_energy_max_ratio` | 0.60 | 桨补能上限（×mg，= 39.4 N） |
| `prop_energy_apex_fade_vz` | 0.30 | apex 前滚降的 vz 窗口 |
| `prop_base/stance_base_thrust_ratio` | 0.0103 | = PWM 1100 怠速基座 |
| `prop_att_thrust_max_each_n` | 5.0 | 姿态差分每桨抬升上限 |
| `flight_kv` | 0.08 | Raibert 落点**纯反馈**增益（中性点 T_st/2 自动算） |
| `flight_vel_kv` | 7.0 | 空中倾斜环带宽（辅助刹车力度） |
| `flight_vel_tilt_max_deg` | 18 | 倾角上限（每度都要落地前还清） |
| `flight_vel_tilt_slew_dps` | 180 | 倾斜斜坡速率（建立与回平同一速率） |
| `flight_level_settle_s` | 0.12 | 落地前回平余量 |
| `prop_descent_brake_ratio` | 0.10 | 下降段刹车 collective 额度（×mg，0=关） |
| `prop_descent_brake_ev_mps` | 0.40 | 达到满额刹车授权的速度误差 |
| `flight_kR / flight_kW` | 60 / 9 | 飞行姿态 PD（跟踪倾斜参考） |

## 9. 关键遥测列

| 列 | 含义 |
|---|---|
| `energy_comp_fz` | 腿 PUSH 弹簧超出普通阻抗的能量注入力 (N) |
| `prop_energy_fz` | 桨补能 collective（含飞行淡出后实际值, N） |
| `prop_att_scale` | 姿态差分交付比例（<1 = 被抬升上限削了） |
| `fl_tilt_cmd_deg` / `fl_zb_des_x/y` | PogoX 倾斜命令角与方向 |
| `fl_ev_xy` | 飞行段水平速度误差范数 \(\|\hat v - v_{des}\|\) (m/s) |
| `fl_lat_force_n` | 倾斜实际交付的侧向力 \(F_z\tan\theta\) (N) |
| `nrc_h_trim` | 逐跳 apex 返回映射的高度目标 trim |
| `flight_vel_w` | IMU 外推的飞行速度（不锁存） |
| `tau_out_scale_applied` | 腿力矩比例限幅（持续 <1 = 腿饱和） |

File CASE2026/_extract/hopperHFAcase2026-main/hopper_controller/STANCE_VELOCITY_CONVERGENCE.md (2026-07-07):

# STANCE Phase 速度收敛机制 + Baseline 参数

> NOTE: 当前 SRB-QP-only 版本已移除 MPC，本文件仅作历史参考。

## 速度收敛机制（两层）

### 1) **MPC 路径**（主要，当 MPC 求解成功时）

**参考速度生成**（混合策略）：
- **早期 STANCE**（compression）：保持当前速度 `v_hat_w[0:2]`（软着陆，不立即刹车）
- **后期 STANCE**（push）：平滑过渡到 `desired_v_xy_w`（速度收敛目标）

```python
# 混合权重（smoothstep）
wv = smoothstep((t - t_comp) / (stance_T - t_comp))
vx_ref = (1 - wv) * v_hat[0] + wv * desired_v_xy_w[0]
vy_ref = (1 - wv) * v_hat[1] + wv * desired_v_xy_w[1]
```

**MPC 求解**：
- 目标：最小化 `||v - v_ref||^2`（权重 `mpc_w_vxy`）
- 约束：摩擦锥 `|f_xy| <= mu * fz`，竖直力 `fz_min <= fz <= fz_max`
- 输出：`f_ref = [fx, fy, fz]`（GRF 参考）

### 2) **Fallback 路径**（MPC 不可行时）

**PD + PI 控制器**：
```python
err_xy = desired_v_xy_w - v_hat_w[0:2]
fx = m * axy_damp * err_x + m * ki_xy * v_int_xy[0]
fy = m * axy_damp * err_y + m * ki_xy * v_int_xy[1]
# 然后限制在摩擦锥内：|f_xy| <= mu * fz
```

**PI 积分器**（slip-gated）：
- 只在 STANCE 且无滑动时积分（`gate` 基于预测的脚端速度）
- 积分上限：`v_int_max`

### 3) **速度估计融合**（STANCE 时）

**腿运动学测量**：
```python
v_meas_b = -(foot_vrel_b + omega × foot_b)  # body frame
v_meas_w = R_wb @ v_meas_b                  # world frame
```

**融合到 v_hat**（complementary filter）：
```python
# XY: 受 v_fuse_vx_scale 控制（默认 1.0 = 完全信任测量）
v_hat[0] = (1 - a_eff_xy) * v_pred[0] + a_eff_xy * v_meas_w[0]
v_hat[1] = (1 - a_eff_xy) * v_pred[1] + a_eff_xy * v_meas_w[1]
# Z: 完全融合（a_eff）
v_hat[2] = (1 - a_eff) * v_pred[2] + a_eff * v_meas_w[2]
```

**滑动检测（slip gate）**：
- 如果预测的脚端速度 `||v_foot_w_pred||` 很大 → `gate` 变小 → 减少融合权重（避免滑移时错误修正）

---

## 所有 Baseline 参数（默认值）

### **速度收敛控制**

| 参数 | 默认值 | 说明 |
|---|---|---|
| `mpc_w_vxy` | `5.0` | MPC 速度跟踪权重（vx/vy 对称） |
| `axy_damp` | `2.0` | Fallback PD 阻尼增益 (N/(m/s)) |
| `ki_xy` | `3.0` | 速度误差积分增益（对称 XY） |
| `v_int_max` | `0.50` | 积分器上限 (m/s) |
| `v_fuse_vx_scale` | `1.0` | 速度融合缩放（XY 对称，1.0 = 完全信任腿运动学测量） |

### **STANCE 时间/参考**

| 参数 | 默认值 | 说明 |
|---|---|---|
| `stance_T` | `0.38` | STANCE 总时长 (s) |
| `stance_min_T` | `0.10` | 最小 STANCE 时长 (s) |
| `soft_land_tc_max_ratio` | `0.60` | 压缩时间上限 = `ratio * stance_T` |

### **摩擦/力约束**

| 参数 | 默认值 | 说明 |
|---|---|---|
| `mu` | `0.3` | 摩擦系数（用于 `|f_xy| <= mu * fz`） |
| `mpc_fz_min` | `40.0` | MPC 最小竖直 GRF (N) |
| `mpc_fz_max` | `220.0` | MPC 最大竖直 GRF (N)（硬编码） |
| `mpc_w_roll` | `20.0` | MPC roll 姿态跟踪权重 |
| `mpc_w_pitch` | `20.0` | MPC pitch 姿态跟踪权重 |

### **MPC 求解器**

| 参数 | 默认值 | 说明 |
|---|---|---|
| `mpc_dt` | `0.02` | MPC 时间步长 (s) |
| `mpc_N` | `12` | MPC 预测步数 |

### **速度估计器**

| 参数 | 默认值 | 说明 |
|---|---|---|
| `use_hopper4_vxy_estimator` | `False` | 启用 Hopper4 式 XY 速度估计（STANCE 用腿运动学，FLIGHT 保持） |
| `_v_hat_lpf_tau` | `0.05` | 速度融合 LPF 时间常数 (s)（内部变量） |

### **高度/起跳**

| 参数 | 默认值 | 说明 |
|---|---|---|
| `hop_peak_z` | `0.7` | 目标 apex 高度 (m) |
| `hop_z0` | `0.55` | 初始高度 (m) |
| `stance_push_v_to_catch` | `True` | PUSH 阶段强制竖直力下限（确保起跳 vz） |

---

## 速度收敛流程图

```
STANCE 开始
    ↓
[速度估计融合]
v_hat_w ← 融合(IMU预测, 腿运动学测量)
    ↓
[MPC 求解]
v_ref = 混合(v_hat, desired_v)  # 早期保持，后期跟踪
f_ref = MPC.solve(v_ref, ...)   # 最小化 ||v - v_ref||
    ↓
MPC 成功？
    ├─ YES → f_ref = MPC.f0
    └─ NO  → f_ref = PD+PI(desired_v - v_hat)
                ↓
            [摩擦锥限制]
            |f_xy| <= mu * fz
    ↓
[WBC-QP]
GRF = WBC.solve(f_ref, ...)
    ↓
[腿扭矩映射]
tau = J^T * f_leg
    ↓
输出到硬件
```

---

## 调参建议

### **如果速度收敛太慢**：
- 增大 `mpc_w_vxy`（例如 8.0~12.0）
- 增大 `axy_damp`（例如 3.0~5.0）
- 增大 `ki_xy`（例如 5.0~8.0）

### **如果速度收敛振荡**：
- 减小 `ki_xy`（例如 1.0~2.0）
- 减小 `v_int_max`（例如 0.30）
- 检查 `mu` 是否太小（摩擦不够）

### **如果速度估计漂移**：
- 启用 `use_hopper4_vxy_estimator = True`（STANCE 用腿运动学，FLIGHT 保持）
- 检查 `v_fuse_vx_scale`（确保 STANCE 时腿运动学测量被充分信任）

---

## 命令行参数（run_modee.py）

```bash
--mpc-w-vxy 5.0          # MPC 速度跟踪权重
--axy-damp 2.0           # Fallback PD 阻尼
--ki-xy 3.0              # 速度积分增益
--v-int-max 0.50         # 积分器上限
--hopper4-vxy             # 启用 Hopper4 式 XY 速度估计
```

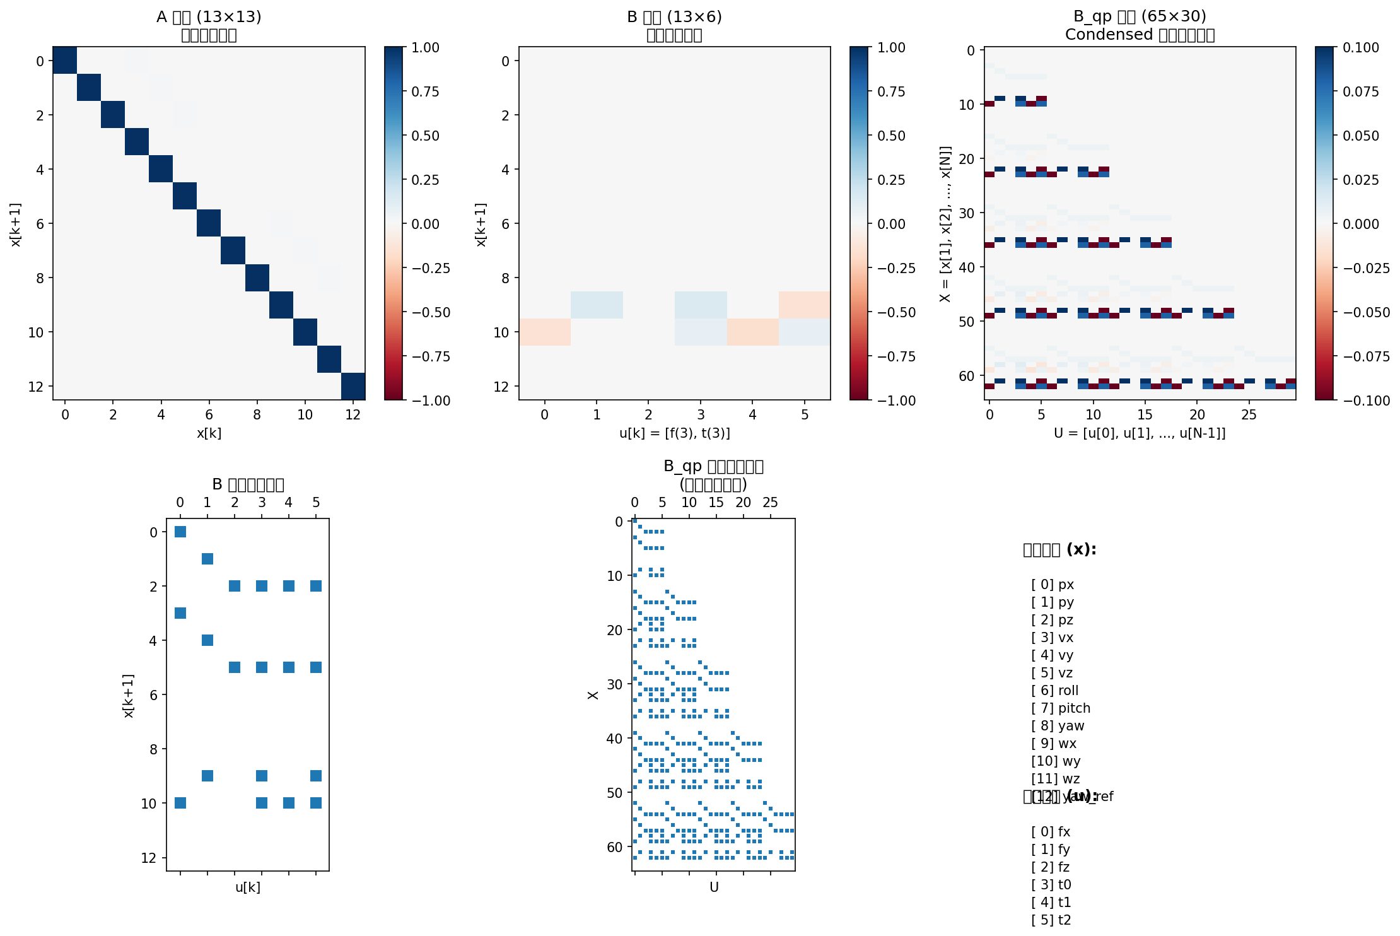
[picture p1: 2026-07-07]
CASE2026/_extract/hopperHFAcase2026-main/hopper_controller/docs/mpc_structure.png

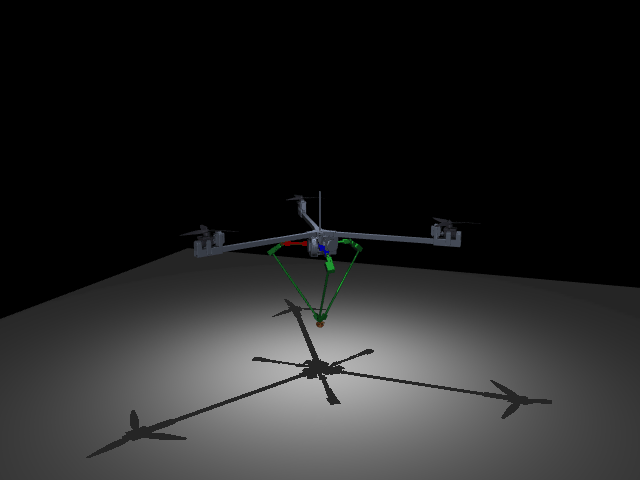
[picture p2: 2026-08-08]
rlmujoco3rsr/demos/pogox_current_1d.gif

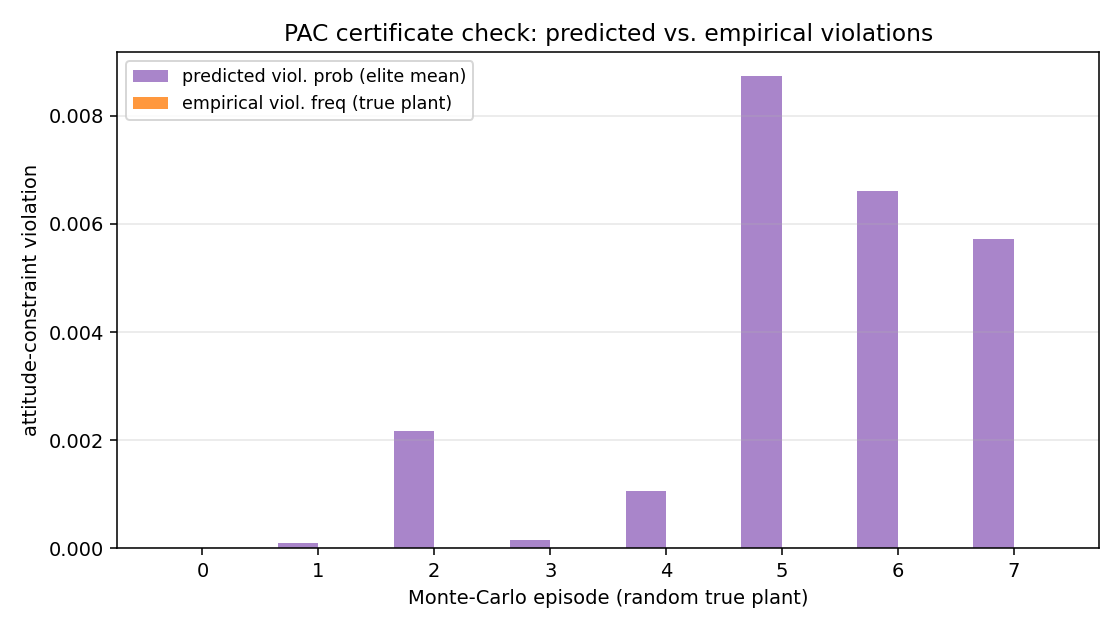
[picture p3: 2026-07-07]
pac_nmpc_demo/out/bound_check.png

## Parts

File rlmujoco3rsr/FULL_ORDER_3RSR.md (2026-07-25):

# Full-Order Dynamics of the 3RSR Hopper (Floating Base, Closed Chain)

Derivation of the full-order constrained dynamics used for low-level torque
feedforward, sitting **below** the SRB/HLIP planning layer:

```
SRB / HLIP (apex states, desired GRF f*, footstep)     <- template layer
        |  f*, base trajectory
        v
Full-order 3RSR constrained inverse dynamics  ->  tau_ff (hip torques)
        + WBC/feedback                        ->  tau_cmd
```

Verified numerically against MuJoCo (`three_leg_3rsr_closed.xml`) by
`full_order_id.py` — see "Verification" at the bottom.

---

## 1. Topology and coordinates

The MuJoCo model realizes each RSR chain as **R(actuated hip) – U(cross pin
`alpha_i` about Y, lower pin `beta_i` about Z) – S(ball `connect` at the shared
foot point)**. Kinematically this is equivalent to the physical 3RSR for foot
positioning (the distal S is exact; the middle S of the physical robot is split
into U here plus the spin freedom absorbed by the ball).

Bodies and generalized velocity `v ∈ R^24`:

| block | symbol | dim | notes |
|---|---|---|---|
| base linear/angular | `v_b = (ṗ_b, ω_b)` | 6 | free joint |
| chain i = 1..3 | `(θ̇_i, α̇_i, β̇_i)` | 3×3 | θ actuated, α/β passive |
| prop servos | `σ̇ ∈ R^3` | 3 | tilt hinges |
| foot free body | `v_f = (ṗ_f, ω_f)` | 6 | free joint |

Configuration `q` (nq = 26 with quaternions). Actuation selector
`S ∈ R^{3×24}` picks the three hip rows.

Effective mobility: 24 dof − 9 loop constraints = 15 in flight
(= base 6 + hips 3 + servos 3 + foot spin 3); in stance, a point contact
removes 3 more → 12.

## 2. Loop-closure constraints

Let `s_i(q) ∈ R^3` be the world position of the distal site of chain i
(function of base pose and `θ_i, α_i, β_i`), and `p_f` the foot-body origin
(the `connect` anchor). The nine holonomic constraints:

```
Φ_i(q) = s_i(q) − p_f = 0,   i = 1,2,3        Φ(q) ∈ R^9
```

Velocity / acceleration level, with `G(q) = ∂Φ/∂v ∈ R^{9×24}`:

```
G v = 0
G v̇ + Ġ v = 0
```

Rows of `G`: `G_i = J_{s_i} − J_{p_f}` (point Jacobians). Because the anchor
sits at the foot origin, `ω_f` does not enter `G` — the foot spin is exactly
the 3-dim internal freedom left by the three ball joints.

## 3. Open-tree equations of motion (Euler–Lagrange / DAE index 3)

Cutting the three balls yields an open tree (base tree + separate foot).
Standard floating-base Lagrangian dynamics plus constraint forces:

```
M(q) v̇ + C(q,v) v + g(q) = Sᵀ τ + B_p(q) u_p + Gᵀ λ + J_cᵀ f_c + d(v)
Φ(q) = 0
```

- `M ∈ R^{24×24}`: joint-space inertia (includes rotor armature),
- `C v + g`: Coriolis/centrifugal + gravity (`qfrc_bias` in MuJoCo),
- `τ ∈ R^3`: hip torques (the unknown feedforward),
- `B_p u_p`: prop thrust + reaction drag + servo torques (known inputs),
- `λ ∈ R^9`: loop-closure multipliers (internal chain forces),
- `f_c ∈ R^3`: ground reaction at the foot contact point, `J_c` its point
  Jacobian (stance only),
- `d(v)`: joint damping (`qfrc_passive`).

This is an index-3 DAE; all uses below work at the acceleration level with
`Φ, GΦ` used for stabilization/projection.

## 4. Constraint elimination (reduced / independent dynamics)

Choose `T(q) ∈ R^{24×15}` whose columns span `ker G` — the independent
quasi-velocities `ν = (v_b, θ̇_1, θ̇_2, θ̇_3, σ̇, ω_f)`, `v = T ν`.
Since `G T = 0`, multipliers drop out:

```
TᵀM T ν̇ + Tᵀ( M Ṫ ν + C v + g − d ) = Tᵀ Sᵀ τ + Tᵀ B_p u_p + Tᵀ J_cᵀ f_c
```

15 ODEs in flight; in stance append `J_c v̇ + J̇_c v = 0` or restrict `T`
further. The dependent rates recover as
`(α̇_i, β̇_i, ṗ_f) = −G_d^{-1} G_ind ν` with the partition `G = [G_ind G_d]`
(`G_d ∈ R^{9×9}` invertible away from chain singularities
`|β_i| < π/4`, which the joint limits enforce).

**Leg Jacobian used by the template layer.** With the base frozen, solving
`G v = 0` for a unit `θ̇_k` yields the foot linear velocity; stacking gives
`J_leg(q) ∈ R^{3×3}`, `ṗ_f^b = J_leg θ̇`. This is the same object the current
controller uses for its static map `τ_static = −J_legᵀ R_bᵀ f*` — i.e. the
static map is the zero-inertia, zero-velocity special case of the equations
above.

## 5. Inverse dynamics feedforward

### 5.1 Stance (push-off / compression)

Inputs from the SRB layer: desired base acceleration `v̇_b*` (or desired GRF
`f*`), foot anchored. Steps at each control tick:

1. **Consistent accelerations.** Solve the linear system
   `G v̇* = −Ġ v`, `J_c v̇* = −J̇_c v`, rows of `v̇*` at (base, servos)
   pinned to the reference — a 24-var linear solve for the passive-joint and
   foot accelerations.
2. **Torques + internal forces.** With `v̇*` known, the dynamics are linear in
   the unknowns `x = (τ, λ, f_c) ∈ R^{15}`:

```
A x = r,   A = [ Sᵀ  Gᵀ  J_cᵀ ] ∈ R^{24×15}
r = M v̇* + C v + g − d − B_p u_p
```

   24 equations, 15 unknowns: solve least-squares. The residual lives in the
   rows not spanned by `A` (foot spin + base rows unreachable given `f*`);
   its norm is a **dynamic-consistency check** on the reference — large
   residual means the SRB layer asked for something the full model cannot do.

3. `τ_ff = x_{1:3}`; feedback (existing SLX/WBC loop) is added on top.

### 5.2 Flight (swing retraction)

Same system without the `J_cᵀ f_c` column; prescribe hip trajectory
`θ̈*` and thrust `u_p`, solve for `τ` — this replaces the pure PD swing
torque with inertia-aware tracking (matters at fast retraction, where the
0.396 m lower legs generate real Coriolis load).

### 5.3 Degeneration to SRB (paper lemma)

Taking leg + foot inertias → 0 in the reduced dynamics, rows 1–6 collapse to

```
m_b p̈_b = m_b g + f_c + Σ R_thrust,i u_i
I_b ω̇_b + ω_b × I_b ω_b = r_c × f_c + Σ (moments of thrust)
```

and the hip rows collapse to `τ = J_legᵀ R_bᵀ f_c` — exactly the SRB + static
Jacobian map used today. So the template layer is the provable zero-leg-mass
limit of the full-order model, and the feedforward correction
`τ_ff − τ_static` is entirely leg-inertia/Coriolis effects.

## 6. Analytical (closed-form) derivation

`derive_full_order_sympy.py` derives every term of Sec. 3 **symbolically**
(SymPy); this is the version citable in a paper as an analytical model.

**Coordinates.** To keep plain Lagrangian mechanics (no quaternion
quasi-velocity bookkeeping), both free bodies use Euler ZYX angles:

```
q = [ p_b, (φ,θ,ψ)_b, (θ_i,α_i,β_i)_{i=1..3}, σ_{1..3}, p_f, (φ,θ,ψ)_f ] ∈ R^24
```

**Method (per body, closed form).** World pose of each of the 14
mass-carrying bodies is a short chain of fixed transforms and joint
rotations. From `p_com,b(q)` and `R_b(q)`:

```
Jv_b = ∂p_com,b/∂q                       (linear point Jacobian)
ω_b  = unskew(Ṙ_b R_bᵀ) = Jw_b(q) q̇      (angular Jacobian)

M(q)   = Σ_b  m_b Jv_bᵀJv_b + Jw_bᵀ I_b^w Jw_b      + diag(armature)
h(q,q̇) = Σ_b  Jv_bᵀ m_b (a_b^vp − g) + Jw_bᵀ (I_b^w α_b^vp + ω_b×I_b^w ω_b)
```

with `a^vp, α^vp` the velocity-product accelerations (time derivatives of
`v, ω` at `q̈ = 0`). `Φ(q)` and `G = ∂Φ/∂q` come from the symbolic chain-tip
positions. The **thrust input matrix** is likewise closed form: rotor i
produces force `u_i d_i(q)` and reaction drag `±k_m u_i d_i(q)` along the
tilted thrust axis `d_i = R_prop,i(q) e_x`, so

```
B_p(q)[:,i] = Jv_prop,iᵀ d_i + k_m,i Jw_prop,iᵀ d_i        (k_m = ±0.018 m)
```

Numeric parameters (masses, COMs, inertia tensors, fixed transforms, axes,
armature) are read from the compiled MuJoCo model, so structure is symbolic
while parameters cannot drift from the plant.

**Impact map (hybrid model, for the paper).** At touchdown with pre-impact
velocity `v⁻`, the post-impact velocity solves the plastic-impact KKT system
with the stacked constraint `Ĝ = [G; J_c]`:

```
[ M   Ĝᵀ ] [ v⁺ ]   [ M v⁻ ]
[ Ĝ   0  ] [ −Λ ] = [   0  ]
```

**MuJoCo convention bridge.** Verification and any state exchange use the
velocity map `v_mj = E(q) q̇` (identity except the two 3×3 Euler-rate →
angular-velocity blocks). Testing both candidates confirmed MuJoCo free
joints use **linear velocity in world frame, angular velocity in body
frame** (the world-frame assumption fails at 1e-1 level, body frame agrees
to 1e-16).

**Verification against MuJoCo** (random `(q, q̇, q̈)`, base/foot poses and
rates fully excited; max abs error over all entries):

| quantity | max error |
|---|---|
| `M(q)` vs `Eᵀ M_mj E` | 5.3e-16 |
| full inverse dynamics `M q̈ + h` vs mapped MuJoCo ID | 1.4e-14 |
| `G(q)` vs mapped site Jacobians | 5.1e-16 |
| `B_p(q)` vs differenced `qfrc_actuator` | 1.8e-15 |

**Generated code.** The derivation script emits `gen_full_order_dyn.py`
(pure numpy, no sympy at runtime): `mass_matrix`, `bias_force`,
`constraint_jac`, `input_matrix`, `vel_map_body/world`. Generated module
re-verified against MuJoCo to 7e-16. Timings (Python, single call):
`M` 0.40 ms, `h` 0.61 ms, `G` 0.054 ms, `B_p` 0.028 ms — usable as-is at
500 Hz feedforward; for a strict 1 kHz budget evaluate `M`/`h` at 500 Hz or
port the generated file to C (mechanical translation).

**Scope caveat (for paper claims).** The model realizes each physical RSR
chain as R (actuated hip) – U (cross + lower pins) – S (ball at the shared
foot), which is the standard kinematic substitution for foot positioning;
before claiming "full-order dynamics of the physical robot", confirm against
CAD that joint axes/offsets match, and identify inertial parameters on
hardware (the structure stays valid; only parameters change). Actuator rotor
dynamics and friction are not included beyond armature.

## 6b. Numerical realization (MuJoCo-backed)

`full_order_id.py` implements Sec. 5 against the MuJoCo model directly —
the same equations with model terms read numerically:

- `M` ← `mj_fullM`, `C v + g` ← `qfrc_bias`, `d` ← `qfrc_passive`,
- `G` ← site point-Jacobian differences (`mj_jacSite`),
- contact `J_c` ← `mj_jac` at the active foot contact,
- known actuators (servos, thrusts) ← `qfrc_actuator` rows,
- least-squares solve of `A x = r` per tick (~24×15, microseconds).

Use this in sim experiments; use `gen_full_order_dyn.py` (Sec. 6) where an
analytical, MuJoCo-free implementation is wanted (paper, onboard runtime).

## 7. Verification (torque replay)

Protocol in `full_order_id.py`:

1. Run a prescribed squat/hop motion with the model's own position actuators;
   record `(q, v, ctrl)` each step.
2. At each frame recompute `v̇` by `mj_forward`, then solve Sec. 5.2's system
   with `τ` **unknown** and compare against the torque MuJoCo's actuators
   actually applied.
3. Also compute `τ_static = J_legᵀ R_bᵀ f_c` from the measured GRF and compare
   — the gap quantifies what full-order feedforward buys during push-off.

Results (`demos/full_order_id_verify.png`, `demos/full_order_id_verify_3hz.png`):

| motion | true τ range | full-order ID RMS err | static Jac map RMS err |
|---|---|---|---|
| 1.5 Hz squat (always in stance) | ±4.8 Nm | **0.0000 Nm** | 0.52 Nm |
| 3.0 Hz squat→hopping (flight phases) | ±8.8 Nm | **0.0000 Nm** | 2.18 Nm |

- Full-order ID reconstructs the actuator torque to machine precision from
  `(q, v, v̇)` alone, in both stance and flight, including through touchdown
  impacts — the constraint structure (Sec. 3–5) is exact for this plant.
- It simultaneously recovers the GRF as a by-product (`f_c` unknown matches
  the measured contact force), i.e. the same solve doubles as a
  **model-based contact force estimator** — usable to replace/monitor the
  touch sensor on hardware.
- The static Jacobian map (today's controller feedforward) is fine
  quasi-statically but degrades to ~2.2 Nm RMS with 10–15 Nm transient spikes
  at touchdown when the motion is dynamic — that gap is precisely the
  leg-inertia/Coriolis term the full-order feedforward adds (Sec. 5.3).

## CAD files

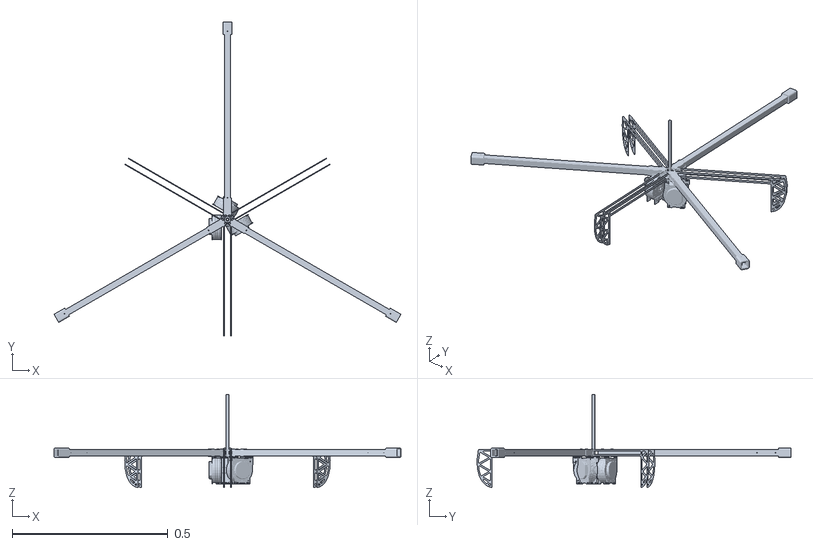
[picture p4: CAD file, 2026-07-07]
CASE2026/_extract/hopperHFAcase2026-main/model/meshes/base_link.STL
1.11 x 1.01 x 0.3

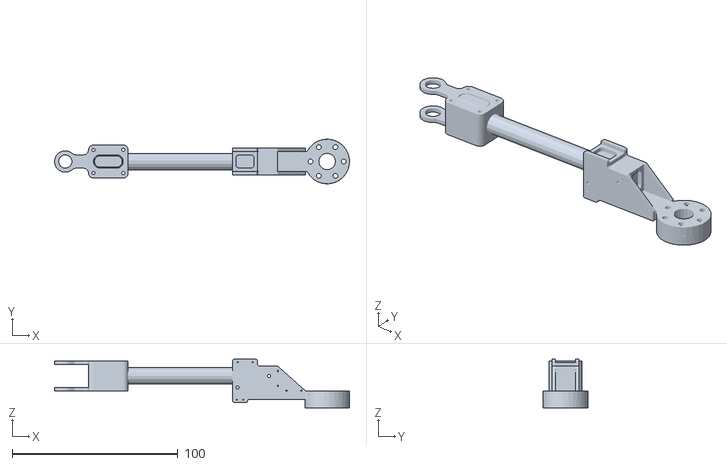
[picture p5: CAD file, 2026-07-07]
rlmujoco3rsr/upperleg.STL
178.0 x 27.0 x 29.3

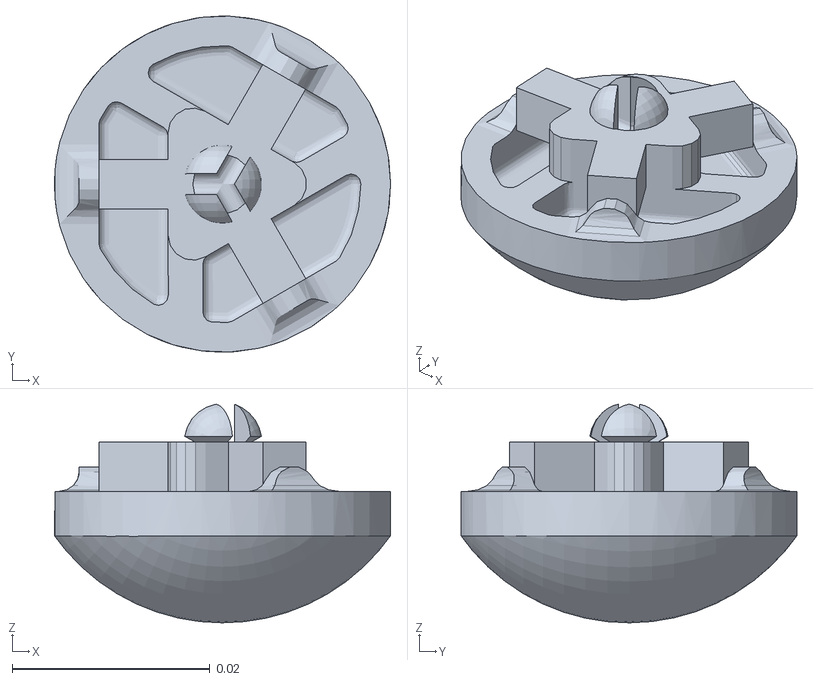
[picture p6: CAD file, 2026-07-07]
CASE2026/_extract/hopperHFAcase2026-main/model/meshes/Foot_Link.STL
0.034 x 0.034 x 0.0221

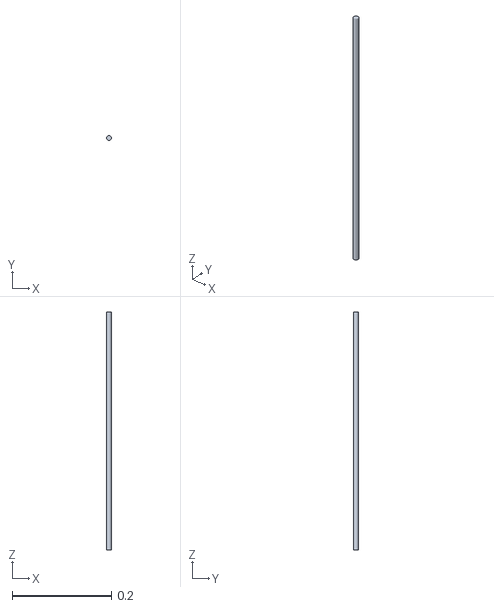
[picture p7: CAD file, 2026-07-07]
pac_nmpc_demo/model/meshes/Leg_Link.STL
0.0098 x 0.0098 x 0.48

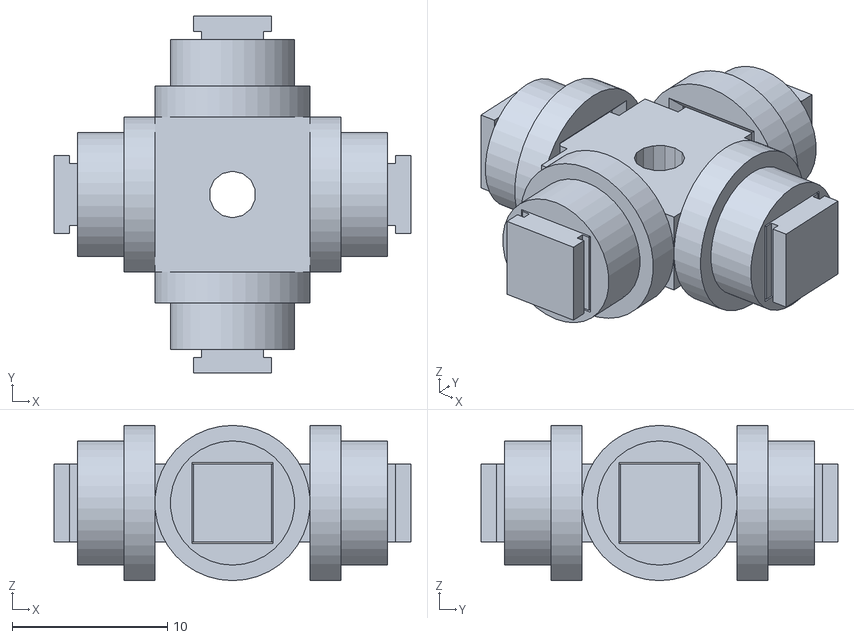
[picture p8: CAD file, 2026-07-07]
rlmujoco3rsr/joint.STL
23.0 x 23.0 x 10.0

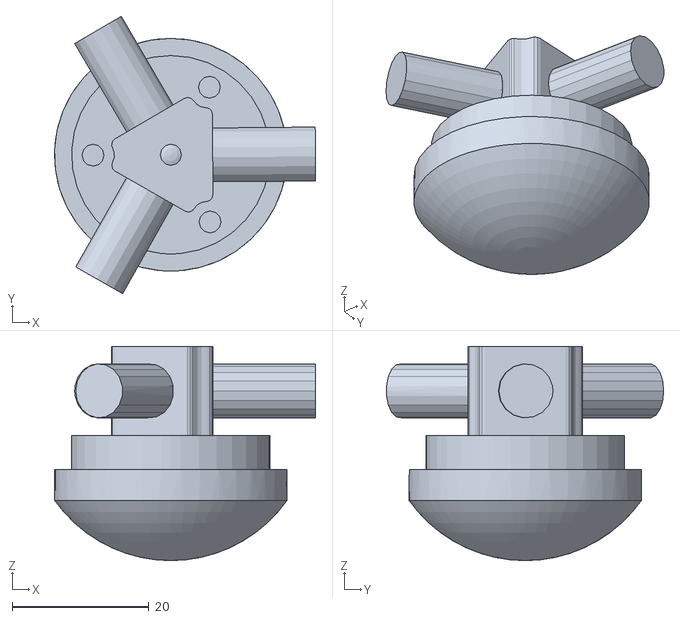
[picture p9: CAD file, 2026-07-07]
rlmujoco3rsr/footv5.STL
38.1 x 40.5 x 31.3

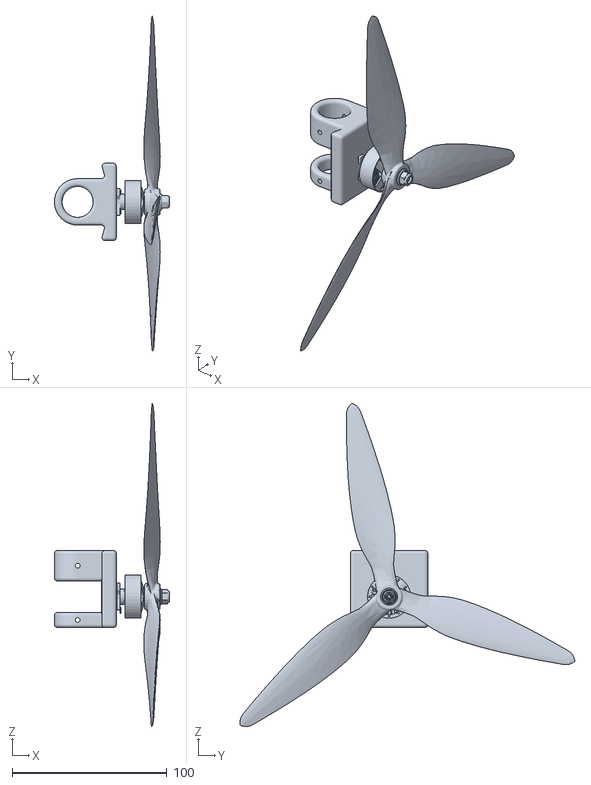
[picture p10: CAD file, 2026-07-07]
rlmujoco3rsr/propellerlink_light.STL
74.4 x 216.4 x 208.7

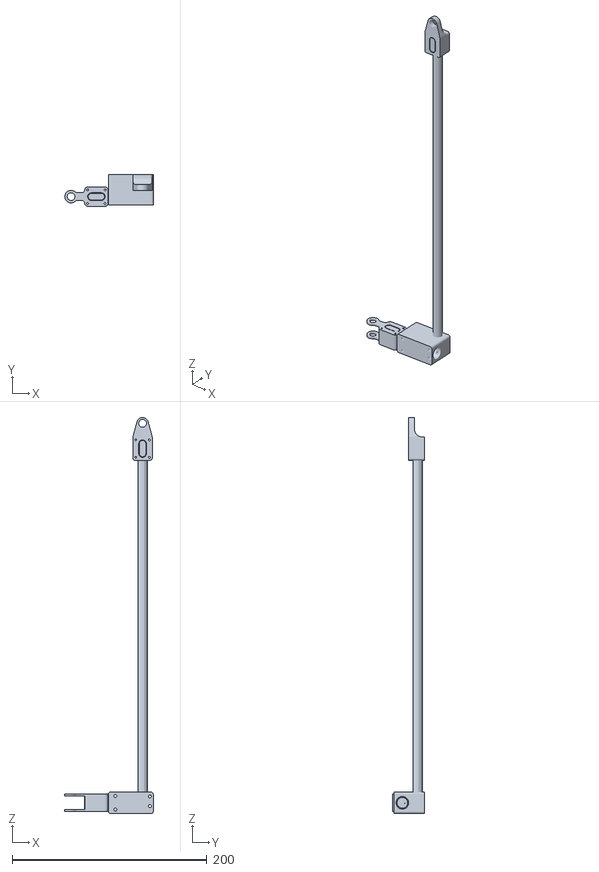
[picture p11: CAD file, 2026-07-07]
rlmujoco3rsr/lowerleg.STL
91.0 x 32.6 x 407.0

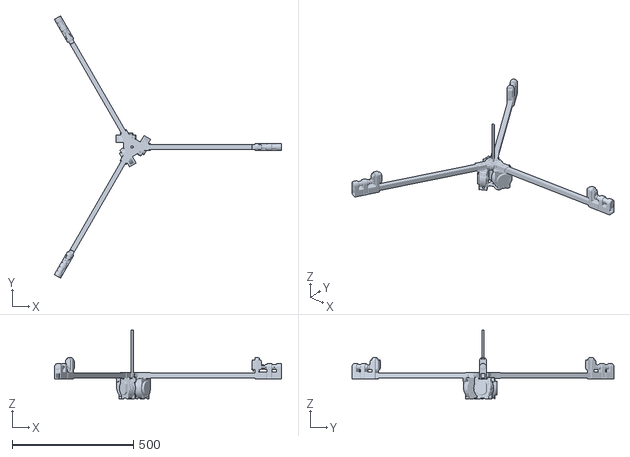
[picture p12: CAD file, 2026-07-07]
rlmujoco3rsr/upperbody_light.STL
937.8 x 1082.2 x 284.1

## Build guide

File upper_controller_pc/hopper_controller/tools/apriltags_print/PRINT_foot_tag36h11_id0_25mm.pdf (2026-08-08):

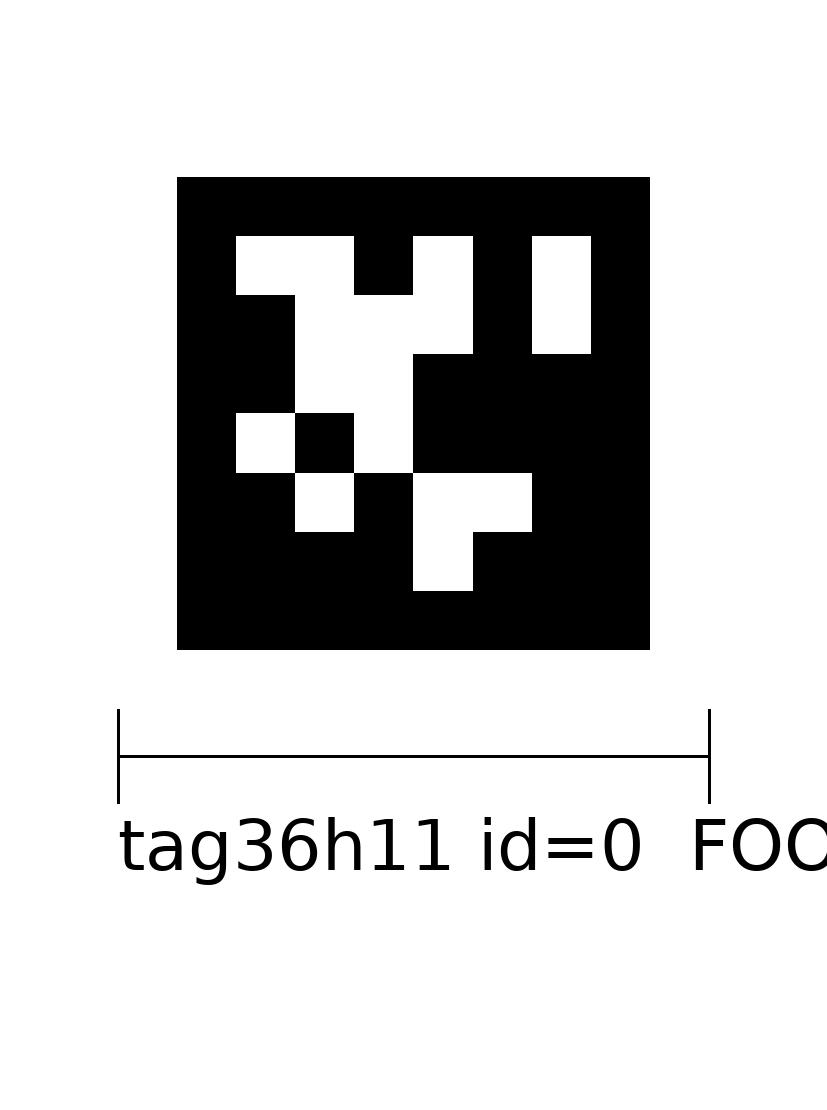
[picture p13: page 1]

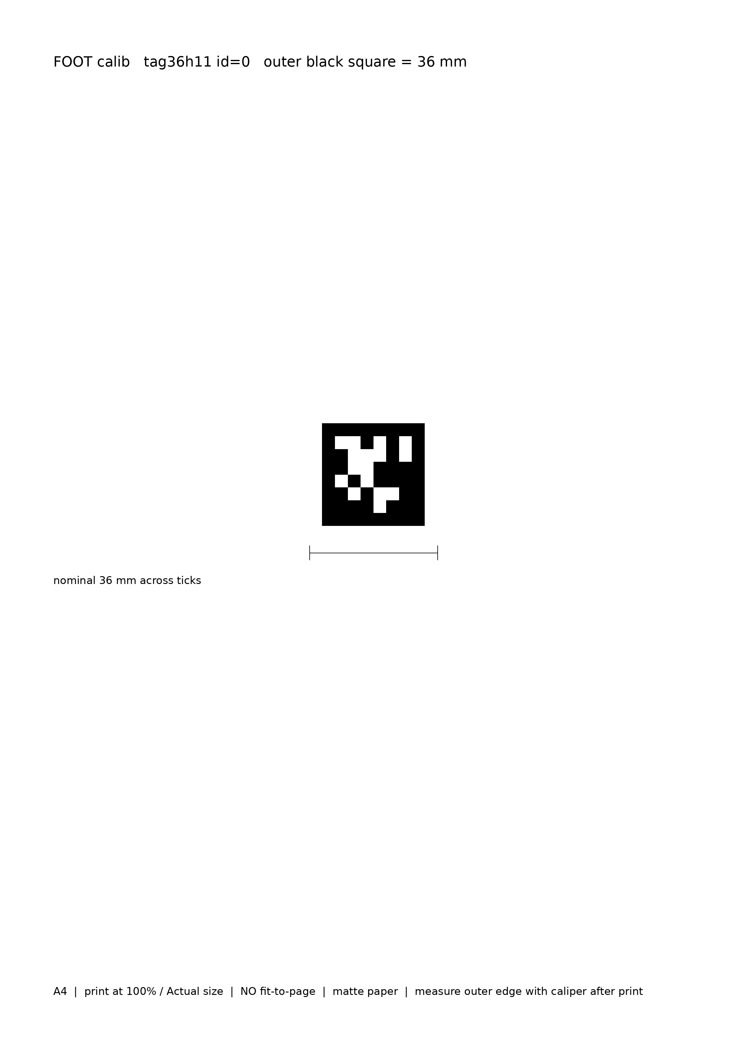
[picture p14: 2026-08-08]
upper_controller_pc/hopper_controller/tools/apriltags_print/PRINT_foot_tag36h11_id0_36mm_A4.png

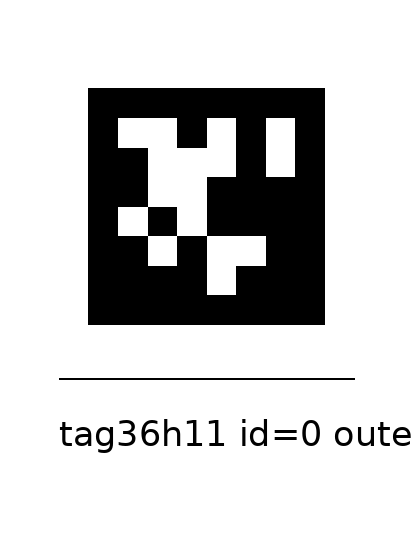
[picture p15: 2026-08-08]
upper_controller_pc/hopper_controller/tools/apriltags_print/PRINT_foot_tag36h11_id0_25mm.png

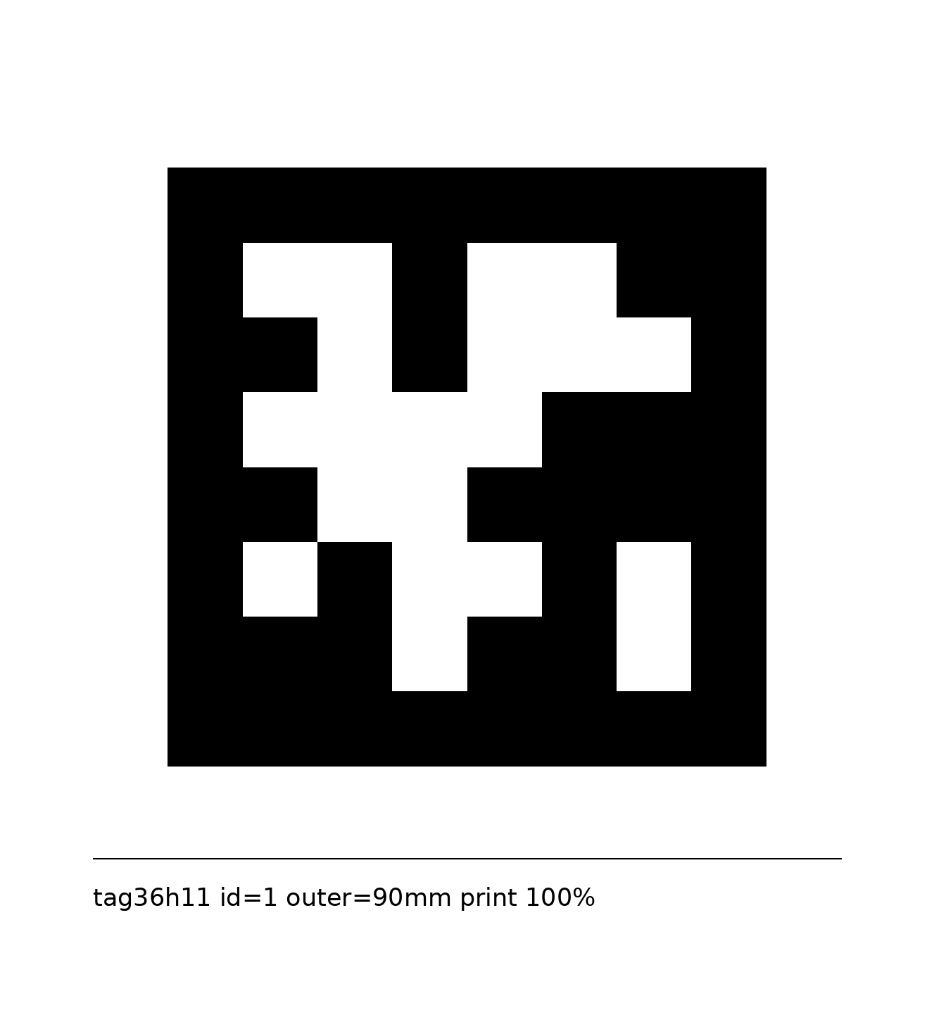
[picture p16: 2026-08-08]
upper_controller_pc/hopper_controller/tools/apriltags_print/PRINT_box_tag36h11_id1_90mm.png

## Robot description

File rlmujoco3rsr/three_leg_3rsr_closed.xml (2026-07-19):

<mujoco model="three_leg_3rsr_closed">
  <compiler angle="radian" meshdir="." autolimits="true"/>
  <option timestep="0.0005" gravity="0 0 -9.81" iterations="50" tolerance="1e-8"/>

  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

  <default>
    <joint armature="0.01" damping="0.05"/>
    <position kp="15" kv="3"/>
    <default class="legmesh">
      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
    </default>
  </default>

  <worldbody>
    <light pos="0 0 2" dir="0 0 -1"/>
    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

    <body name="base" pos="0 0 0.6">
      <freejoint name="root"/>
      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
      <body name="leg1" quat="0 0 0 1">
        <body name="hip1" pos="0.02424 0 0">
          <body name="upper1" quat="0 0 0 1">
            <joint name="ctrl_joint_1" type="hinge" axis="0 1 0" range="-1.5708 1.0472" damping="0.05"/>
            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
            <body name="cross1" pos="-0.158 0 0">
              <joint name="cross_pin_1" type="hinge" axis="0 1 0" damping="0.01"/>
              <inertial pos="0 0 0" mass="0.0073" diaginertia="7.28e-7 7.28e-7 7.28e-7"/>
              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
              <body name="lower1" pos="0 0 0">
              <joint name="lower_pin_1" type="hinge" axis="0 0 1" range="-0.7854 0.7854" damping="0.01"/>
              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
              </body>
            </body>
          </body>
        </body>
      </body>

      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
      <body name="leg2" quat="0.8660254 0 0 -0.5">
        <body name="hip2" pos="0.02424 0 0">
          <body name="upper2" quat="0 0 0 1">
            <joint name="ctrl_joint_2" type="hinge" axis="0 1 0" range="-1.5708 1.0472" damping="0.05"/>
            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
            <body name="cross2" pos="-0.158 0 0">
              <joint name="cross_pin_2" type="hinge" axis="0 1 0" damping="0.01"/>
              <inertial pos="0 0 0" mass="0.0073" diaginertia="7.28e-7 7.28e-7 7.28e-7"/>
              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
              <body name="lower2" pos="0 0 0">
              <joint name="lower_pin_2" type="hinge" axis="0 0 1" range="-0.7854 0.7854" damping="0.01"/>
              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
              </body>
            </body>
          </body>
        </body>
      </body>

      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
      <body name="leg3" quat="0.8660254 0 0 0.5">
        <body name="hip3" pos="0.02424 0 0">
          <body name="upper3" quat="0 0 0 1">
            <joint name="ctrl_joint_3" type="hinge" axis="0 1 0" range="-1.5708 1.0472" damping="0.05"/>
            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
            <body name="cross3" pos="-0.158 0 0">
              <joint name="cross_pin_3" type="hinge" axis="0 1 0" damping="0.01"/>
              <inertial pos="0 0 0" mass="0.0073" diaginertia="7.28e-7 7.28e-7 7.28e-7"/>
              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
              <body name="lower3" pos="0 0 0">
              <joint name="lower_pin_3" type="hinge" axis="0 0 1" range="-0.7854 0.7854" damping="0.01"/>
              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
              </body>
            </body>
          </body>
        </body>
      </body>

      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
      <body name="proparm1" quat="1 0 0 0">
        <body name="prop1" pos="0.56705 0 0.0866" quat="0 0.7071068 0 0.7071068">
          <joint name="servo_1" type="hinge" axis="0 0 1" range="-1.5708 1.5708" damping="0.2"/>
          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
          <inertial pos="0 0 0" mass="0.109" diaginertia="1.456e-4 1.456e-4 1.456e-4"/>
          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
        </body>
      </body>
      <body name="proparm2" quat="0.5 0 0 0.8660254">
        <body name="prop2" pos="0.56705 0 0.0866" quat="0 0.7071068 0 0.7071068">
          <joint name="servo_2" type="hinge" axis="0 0 1" range="-1.5708 1.5708" damping="0.2"/>
          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
          <inertial pos="0 0 0" mass="0.109" diaginertia="1.456e-4 1.456e-4 1.456e-4"/>
          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
        </body>
      </body>
      <body name="proparm3" quat="-0.5 0 0 0.8660254">
        <body name="prop3" pos="0.56705 0 0.0866" quat="0 0.7071068 0 0.7071068">
          <joint name="servo_3" type="hinge" axis="0 0 1" range="-1.5708 1.5708" damping="0.2"/>
          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
          <inertial pos="0 0 0" mass="0.109" diaginertia="1.456e-4 1.456e-4 1.456e-4"/>
          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
        </body>
      </body>
    </body>

    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
    <body name="foot" pos="0 0 0.231055">
      <freejoint name="foot_free"/>
      <inertial pos="0 0 0" mass="0.036" diaginertia="7.28e-6 7.28e-6 7.28e-6"/>
      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
    </body>
  </worldbody>

  <equality>
    <connect site1="foot_center" site2="foot_site_1" solref="0.002 1" solimp="0.99 0.999 1e-4 0.5 2"/>
    <connect site1="foot_center" site2="foot_site_2" solref="0.002 1" solimp="0.99 0.999 1e-4 0.5 2"/>
    <connect site1="foot_center" site2="foot_site_3" solref="0.002 1" solimp="0.99 0.999 1e-4 0.5 2"/>
  </equality>

  <actuator>
    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
    <position name="ctrl_motor_1" joint="ctrl_joint_1" kp="100" kv="3" forcerange="-25 25" ctrlrange="-1.5708 1.0472"/>
    <position name="ctrl_motor_2" joint="ctrl_joint_2" kp="100" kv="3" forcerange="-25 25" ctrlrange="-1.5708 1.0472"/>
    <position name="ctrl_motor_3" joint="ctrl_joint_3" kp="100" kv="3" forcerange="-25 25" ctrlrange="-1.5708 1.0472"/>
    <position name="servo_motor_1" joint="servo_1" ctrlrange="-1.5708 1.5708"/>
    <position name="servo_motor_2" joint="servo_2" ctrlrange="-1.5708 1.5708"/>
    <position name="servo_motor_3" joint="servo_3" ctrlrange="-1.5708 1.5708"/>
    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
    <general name="thrust_1" site="thrust_site_1" gear="1 0 0 0.018 0 0" gainprm="1 0 0" ctrlrange="0 10"/>
    <general name="thrust_2" site="thrust_site_2" gear="1 0 0 0.018 0 0" gainprm="1 0 0" ctrlrange="0 10"/>
    <general name="thrust_3" site="thrust_site_3" gear="1 0 0 -0.018 0 0" gainprm="1 0 0" ctrlrange="0 10"/>
  </actuator>

  <sensor>
    <accelerometer name="imu_accel" site="imu"/>
    <gyro name="imu_gyro" site="imu"/>
    <framequat name="imu_quat" objtype="site" objname="imu"/>
    <framepos name="base_pos" objtype="site" objname="imu"/>
    <framelinvel name="base_linvel" objtype="site" objname="imu"/>
    <jointpos name="hip1_pos" joint="ctrl_joint_1"/>
    <jointpos name="hip2_pos" joint="ctrl_joint_2"/>
    <jointpos name="hip3_pos" joint="ctrl_joint_3"/>
    <jointvel name="hip1_vel" joint="ctrl_joint_1"/>
    <jointvel name="hip2_vel" joint="ctrl_joint_2"/>
    <jointvel name="hip3_vel" joint="ctrl_joint_3"/>
    <jointpos name="servo1_pos" joint="servo_1"/>
    <jointpos name="servo2_pos" joint="servo_2"/>
    <jointpos name="servo3_pos" joint="servo_3"/>
    <touch name="foot_touch_sensor" site="foot_touch"/>
  </sensor>

  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
</mujoco>

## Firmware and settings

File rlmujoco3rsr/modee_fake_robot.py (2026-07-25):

"""Fake robot for the CURRENT runtime stack (robot_runtime/upper_controller_pc).

Speaks the same LCM protocol as the real Jetson driver + PX4 DDS bridge, but
simulates the 3-RSR closed-chain MuJoCo model. Conventions match TODAY's
core.py / lcm_controller.py / px4_dds_bridge.py (NOT the CASE-era ones):

  - body frame = leg FK frame = IMU frame = FRD (+X fwd, +Y right, +Z down)
  - world NED-like (+Z down); level+stationary acc = [0,0,-9.81] (specific force)
  - NO gyro_y sign flip (the old flip pair was removed from bridge+controller)
  - forward_kinematics.py with IDENTITY motor permutation, yaw offset 0

Joint mapping (recalibrated by _modee_calib.py against the runtime FK, err ~4mm):
    q_lcm[i]  = Q0_LCM - (q_sim[PERM[i]] - HOME_SIM)        (sign = -1)
    qd_lcm[i] = -qd_sim[PERM[i]]
    tau_sim[PERM[i]] = -tau_ff_lcm[i]
    frame map: v_frd = diag(1,-1,-1) @ Rz(+90 deg) @ v_sim

Run (pair with run_modee_on_sim.py):
    python3 modee_fake_robot.py --duration-s 20 --drop-start-s 1.5
"""
import os
os.environ.setdefault("MUJOCO_GL", "egl")
import argparse
import sys
import time

import mujoco
import numpy as np
import lcm

from runtime_paths import CONTROLLER_DIR, LCM_TYPES_DIR
sys.path.append(LCM_TYPES_DIR)
sys.path.append(CONTROLLER_DIR)

from python.hopper_data_lcmt import hopper_data_lcmt    # type: ignore
from python.hopper_cmd_lcmt import hopper_cmd_lcmt      # type: ignore
from python.hopper_imu_lcmt import hopper_imu_lcmt      # type: ignore
from python.gamepad_lcmt import gamepad_lcmt            # type: ignore
from python.motor_pwm_lcmt import motor_pwm_lcmt        # type: ignore
from modee.core import ModeEConfig  # type: ignore

XML = os.path.join(os.path.dirname(os.path.abspath(__file__)), "three_leg_3rsr_closed.xml")

# ---- calibration (see _modee_calib.py output, 2026-07-04) ----
# NOTE: the 3-RSR leg has C3 (120 deg) symmetry, so the FK-deflection calibration
# admits THREE equivalent (PERM, yaw) branches. Only one is consistent with the
# FIXED IMU yaw below; the touchdown-direction probe selects it (MFR_PERM_BRANCH).
HOME_SIM = -0.060299
Q0_LCM = 0.0900
_PERM_BRANCHES = ((0, 2, 1), (1, 0, 2), (2, 1, 0))  # C3 cyclic relabelings
PERM = _PERM_BRANCHES[int(os.environ.get("MFR_PERM_BRANCH", "0"))]
JOINT_SIGN = -1.0
YAW_FRD = np.deg2rad(90.0)

HIP_QPOS = [7, 10, 13]
HIP_QVEL = [6, 9, 12]

_c, _s = np.cos(YAW_FRD), np.sin(YAW_FRD)
# v_frd = M @ v_sim  (sim base/world Z-up -> FRD/NED-like Z-down); M is proper (det=+1)
M_FRD = np.diag([1.0, -1.0, -1.0]) @ np.array([[_c, -_s, 0], [_s, _c, 0], [0, 0, 1.0]])

# current core.py prop convention (FRD), confirmed 2026-07-18:
#   arm 0 (-90deg, (0,-L))   -> PWM[2] / M2
#   arm 1 (+150deg, (-x,+y)) -> PWM[3] / M3
#   arm 2 (+30deg, (+x,+y))  -> PWM[1]
PROP_PWM_ARM_ANGLE_FRD = {2: -90.0, 3: +150.0, 1: +30.0}
TAU_LIM = float(os.environ.get("FAKE_TAU", "25.0"))


def quat_to_R(q):
    w, x, y, z = np.asarray(q, dtype=float) / max(1e-12, float(np.linalg.norm(q)))
    return np.array([
        [1 - 2 * (y * y + z * z), 2 * (x * y - z * w), 2 * (x * z + y * w)],
        [2 * (x * y + z * w), 1 - 2 * (x * x + z * z), 2 * (y * z - x * w)],
        [2 * (x * z - y * w), 2 * (y * z + x * w), 1 - 2 * (x * x + y * y)],
    ])


def R_to_quat(R):
    tr = R[0, 0] + R[1, 1] + R[2, 2]
    if tr > 0:
        s = np.sqrt(tr + 1.0) * 2
        return np.array([0.25 * s, (R[2, 1] - R[1, 2]) / s, (R[0, 2] - R[2, 0]) / s, (R[1, 0] - R[0, 1]) / s])
    i = int(np.argmax([R[0, 0], R[1, 1], R[2, 2]]))
    if i == 0:
        s = np.sqrt(1.0 + R[0, 0] - R[1, 1] - R[2, 2]) * 2
        return np.array([(R[2, 1] - R[1, 2]) / s, 0.25 * s, (R[0, 1] + R[1, 0]) / s, (R[0, 2] + R[2, 0]) / s])
    if i == 1:
        s = np.sqrt(1.0 + R[1, 1] - R[0, 0] - R[2, 2]) * 2
        return np.array([(R[0, 2] - R[2, 0]) / s, (R[0, 1] + R[1, 0]) / s, 0.25 * s, (R[1, 2] + R[2, 1]) / s])
    s = np.sqrt(1.0 + R[2, 2] - R[0, 0] - R[1, 1]) * 2
    return np.array([(R[1, 0] - R[0, 1]) / s, (R[0, 2] + R[2, 0]) / s, (R[1, 2] + R[2, 1]) / s, 0.25 * s])


def rpy_zyx(R):
    """Aerospace ZYX rpy from R_wb (FRD->NED), matches core._R_to_rpy_xyz."""
    roll = float(np.arctan2(R[2, 1], R[2, 2]))
    pitch = float(np.arctan2(-R[2, 0], np.sqrt(max(1e-12, R[2, 1] ** 2 + R[2, 2] ** 2))))
    yaw = float(np.arctan2(R[1, 0], R[0, 0]))
    return roll, pitch, yaw


def main():
    ap = argparse.ArgumentParser()
    ap.add_argument("--duration-s", type=float, default=20.0)
    # Gamepad edges must fire AFTER the controller process is up and subscribed,
    # otherwise it misses X (PD legs) / A (props) and never actuates.
    ap.add_argument("--y-at-s", type=float, default=2.5, help="Y edge (log/reset)")
    ap.add_argument("--x-at-s", type=float, default=3.0, help="X edge (PD legs on)")
    ap.add_argument("--a-at-s", type=float, default=3.5, help="A edge (props on)")
    ap.add_argument("--drop-start-s", type=float, default=4.5)
    ap.add_argument("--drop-z", type=float, default=0.55,
                    help="hold height before release; raise for more first-touchdown energy "
                         "(0.55 gives only ~0.10 m foot free-fall with l0=0.455 -> marginal bootstrap)")
    ap.add_argument("--strict-1d", action="store_true",
                    help="lock base xy + attitude every step (pure vertical hopping)")
    ap.add_argument("--strict-2d", action="store_true",
                    help="lock base y + roll + yaw (x-z plane motion, pitch free)")
    ap.add_argument("--init-roll-deg", type=float, default=0.0,
                    help="initial base roll (sim X axis) applied at reset")
    ap.add_argument("--hold-hips", action="store_true",
                    help="keep hip POSITION actuators at home (ignore tau) - prop-only attitude test")
    ap.add_argument("--hold-att-free", action="store_true",
                    help="during pre-drop hold, pin xyz but leave attitude FREE")
    ap.add_argument("--print-roll", action="store_true", help="print roll/pitch trace at 5 Hz")
    ap.add_argument("--record-gif", type=str, default=None)
    ap.add_argument("--realtime", action="store_true", default=True)
    ap.add_argument("--floor-mu", type=float, default=None,
                    help="tangential friction of floor AND foot geoms (MuJoCo pairs "
                         "take the elementwise max, so both must be set)")
    ap.add_argument("--total-mass", type=float, default=None,
                    help="uniformly scale all MuJoCo body masses/inertias to this total "
                         "mass. Use the current ModeEConfig.mass_kg for a current-core run.")
    args = ap.parse_args()

    m = mujoco.MjModel.from_xml_path(XML)
    core_defaults = ModeEConfig()
    if args.total_mass is not None:
        m0 = float(np.sum(m.body_mass))
        scale = float(args.total_mass) / max(1e-9, m0)
        m.body_mass[:] *= scale
        m.body_inertia[:] *= scale
        print(f"plant mass scaled {m0:.3f} -> {np.sum(m.body_mass):.3f} kg "
              f"(mass/inertia scale {scale:.3f})")
    if args.floor_mu is not None:
        for gname in ("floor", "foot_collision"):
            gid = mujoco.mj_name2id(m, mujoco.mjtObj.mjOBJ_GEOM, gname)
            m.geom_friction[gid, 0] = float(args.floor_mu)
        print(f"floor/foot tangential friction set to mu={args.floor_mu}")
    # Bidirectional ESC model: controller side maps thrust<0 to pwm<1000 (3D mode);
    # widen the sim thrust actuators so reverse (downforce) actually acts.
    tmax = float(core_defaults.thrust_max_each_n)
    m.actuator_ctrlrange[6:9, 0] = -tmax
    m.actuator_ctrlrange[6:9, 1] = +tmax
    # controller sends torques; bypass hip position actuators (unless --hold-hips)
    if not args.hold_hips:
        m.actuator_gainprm[0:3, :] = 0.0
        m.actuator_biasprm[0:3, :] = 0.0
    d = mujoco.MjData(m)
    key = mujoco.mj_name2id(m, mujoco.mjtObj.mjOBJ_KEY, "home")
    mujoco.mj_resetDataKeyframe(m, d, key)
    home_ctrl = m.key_ctrl[key].copy()
    dt = m.opt.timestep
    if abs(args.init_roll_deg) > 1e-9:
        a2 = 0.5 * np.deg2rad(args.init_roll_deg)
        d.qpos[3:7] = [np.cos(a2), np.sin(a2), 0.0, 0.0]
        mujoco.mj_forward(m, d)

    # foot body/geom ids (for contact-point slip velocity)
    foot_bid = mujoco.mj_name2id(m, mujoco.mjtObj.mjOBJ_BODY, "foot")
    foot_gid = mujoco.mj_name2id(m, mujoco.mjtObj.mjOBJ_GEOM, "foot_collision")
    foot_r = float(m.geom_size[foot_gid, 0])

    # map PWM channels -> sim thrust actuators by arm angle in FRD
    mujoco.mj_forward(m, d)
    pwm_to_act = {}
    for pwm_idx, ang_des in PROP_PWM_ARM_ANGLE_FRD.items():
        best, bdif = None, 1e9
        for i in range(3):
            sid = mujoco.mj_name2id(m, mujoco.mjtObj.mjOBJ_SITE, f"thrust_site_{i+1}")
            p_simbody = d.site_xpos[sid] - d.qpos[0:3]
            p_frd = M_FRD @ p_simbody
            a = np.degrees(np.arctan2(p_frd[1], p_frd[0]))
            dif = abs((a - ang_des + 180) % 360 - 180)
            if dif < bdif:
                bdif, best = dif, i
        pwm_to_act[pwm_idx] = (best, bdif)
    print("PWM ch -> sim thrust actuator:",
          {k: f"thrust_{v[0]+1} (err {v[1]:.0f} deg)" for k, v in pwm_to_act.items()})

    # SIM ISOLATION: default to a loopback-only bus (7669, ttl=0) so the fake
    # robot can NEVER talk to the real Jetson driver (7667, ttl=255). Sweep
    # scripts that export LCM_DEFAULT_URL keep working (env wins).
    lc = lcm.LCM(os.environ.get("LCM_DEFAULT_URL", "udpm://239.255.76.67:7669?ttl=0"))
    tau_lcm = np.zeros(3)
    qd_filt = np.zeros(3)
    pwm_cmd = np.full(6, 1000.0)
    armed = [False]

    def on_cmd(_, buf):
        nonlocal tau_lcm
        tau_lcm = np.array(hopper_cmd_lcmt.decode(buf).tau_ff, dtype=float)

    def on_pwm(_, buf):
        nonlocal pwm_cmd
        msg = motor_pwm_lcmt.decode(buf)
        pwm_cmd = np.array(msg.pwm_values, dtype=float)
        armed[0] = int(msg.control_mode) > 0

    lc.subscribe("hopper_cmd_lcmt", on_cmd)
    lc.subscribe("motor_pwm_lcmt", on_pwm)

    gif_frames = []
    ren = cam = None
    if args.record_gif:
        ren = mujoco.Renderer(m, height=480, width=640)
        cam = mujoco.MjvCamera()
        mujoco.mjv_defaultCamera(cam)
        cam.distance = 2.6
        cam.elevation = -12
        cam.azimuth = 110

    sim_t = 0.0
    next_gp = next_pub = next_frame = 0.0
    base_zs, taus_log, foot_zs, contacts_log = [], [], [], []
    t_wall0 = time.time()
    prev_contact = False
    td_events = []  # (t, v_xy_sim, foot_offset_xy_sim) at each touchdown
    # foot slip accounting (friction-cone experiments): path length of the foot
    # contact point in the ground plane, accumulated per stance
    slip_acc = 0.0
    slip_per_hop = []
    foot_xy_prev = None
    thrust_min_seen, thrust_max_seen = 0.0, 0.0
    # early-stance (touchdown transient) slip: first TD_WIN seconds of each stance,
    # the window the downforce pulse targets (fz still ramping, cone at its tightest)
    TD_WIN = 0.08
    slip_td_acc = 0.0
    slip_td_per_hop = []
    t_td_last = None

    while sim_t < args.duration_s:
        for _ in range(16):
            if lc.handle_timeout(0) <= 0:
                break

        # synthetic gamepad: Y (log/reset) -> X (PD legs) -> A (props on)
        if sim_t >= next_gp:
            gp = gamepad_lcmt()
            stick_x = float(os.environ.get("MFR_STICK_X", "0.0")) if sim_t > float(os.environ.get("MFR_STICK_AT_S", "8.0")) else 0.0
            stick_y = float(os.environ.get("MFR_STICK_Y", "0.0")) if sim_t > float(os.environ.get("MFR_STICK_AT_S", "8.0")) else 0.0
            gp.rightStickAnalog = [stick_x, stick_y]
            gp.leftStickAnalog = [0.0, 0.0]
            gp.y = 1 if args.y_at_s <= sim_t < args.y_at_s + 0.2 else 0
            gp.x = 1 if args.x_at_s <= sim_t < args.x_at_s + 0.2 else 0
            gp.a = 1 if args.a_at_s <= sim_t < args.a_at_s + 0.2 else 0
            lc.publish("gamepad_lcmt", gp.encode())
            next_gp += 0.02

        # joint torques: tau_sim[PERM[i]] = JOINT_SIGN * tau_lcm[i]
        tau_sim = np.zeros(3)
        if armed[0] and not args.hold_hips:
            for i in range(3):
                tau_sim[PERM[i]] = float(np.clip(JOINT_SIGN * tau_lcm[i], -TAU_LIM, TAU_LIM))
        d.qfrc_applied[:] = 0.0
        for j, adr in enumerate(HIP_QVEL):
            d.qfrc_applied[adr] = tau_sim[j]
        if args.hold_hips:
            d.ctrl[0:3] = home_ctrl[0:3]
        d.ctrl[3:6] = home_ctrl[3:6]  # servos frozen

        # Props: use the SAME current ModeEConfig PWM law in both directions.
        # This intentionally does not use the legacy F40 measured table: the current
        # core uses the F100+7in square-root map, so the inverse plant relation is
        # thrust = sign(dpwm) * prop_k_thrust * dpwm^2.
        if armed[0]:
            stop = float(core_defaults.pwm_min_us)
            dpwm = np.asarray(pwm_cmd, dtype=float) - stop
            thr6 = np.sign(dpwm) * float(core_defaults.prop_k_thrust) * np.square(dpwm)
        else:
            thr6 = np.zeros(6)
        d.ctrl[6:9] = 0.0
        for pwm_idx, (act_i, _) in pwm_to_act.items():
            d.ctrl[6 + act_i] = float(np.clip(thr6[pwm_idx], -tmax, tmax))
        thrust_min_seen = min(thrust_min_seen, float(np.min(d.ctrl[6:9])))
        thrust_max_seen = max(thrust_max_seen, float(np.max(d.ctrl[6:9])))

        mujoco.mj_step(m, d)
        if args.strict_1d:
            d.qpos[0:2] = 0
            d.qpos[3:7] = [1, 0, 0, 0]
            d.qvel[0:2] = 0
            d.qvel[3:6] = 0
        elif args.strict_2d:
            # keep x-z plane translation + pitch-about-sim-Y only.
            # NOTE frame map yaw=+90deg: FRD x (controller fwd) = sim -y? Careful:
            # v_frd = diag(1,-1,-1) Rz(90) v_sim -> sim X maps to FRD -Y (lateral),
            # sim Y maps to FRD -X... so controller-plane (FRD x-z) = sim (y,z).
            # Lock sim x + the rotation that couples out of that plane.
            q = np.asarray(d.qpos[3:7], dtype=float)
            R = quat_to_R(q)
            # allowed rotation: about sim X axis (which maps to FRD +Y = pitch axis)
            ang = np.arctan2(R[2, 1], R[1, 1])  # rotation about sim x
            d.qpos[0] = 0
            d.qpos[3:7] = [np.cos(ang / 2), np.sin(ang / 2), 0, 0]
            d.qvel[0] = 0
            d.qvel[4:6] = 0
        if args.drop_start_s > 0 and sim_t < args.drop_start_s:
            d.qpos[0:3] = [0, 0, float(args.drop_z)]
            d.qvel[0:3] = 0
            if args.hold_att_free:
                pass  # attitude left free (prop attitude-loop sign test)
            else:
                d.qpos[3:7] = [1, 0, 0, 0]
                d.qvel[3:6] = 0
        sim_t += dt

        # publish at 1 kHz motor / 500 Hz IMU-equivalent (both at 1kHz is fine)
        if sim_t >= next_pub:
            q_sim = d.qpos[HIP_QPOS]
            qd_sim = np.array([d.qvel[a] for a in HIP_QVEL])
            qd_filt[:] = qd_filt + 0.2 * (qd_sim - qd_filt)  # ~40Hz LPF like AK60 driver

            jd = hopper_data_lcmt()
            jd.q = [float(Q0_LCM + JOINT_SIGN * (q_sim[PERM[i]] - HOME_SIM)) for i in range(3)]
            jd.qd = [float(JOINT_SIGN * qd_filt[PERM[i]]) for i in range(3)]
            jd.tauIq = [float(JOINT_SIGN * tau_sim[PERM[i]]) for i in range(3)]
            lc.publish("hopper_data_lcmt", jd.encode())

            # ---- IMU in FRD/NED (current px4_dds_bridge conventions) ----
            R_wb_sim = quat_to_R(d.qpos[3:7])          # sim body -> sim world (both Z-up)
            R_frd = M_FRD @ R_wb_sim @ M_FRD.T          # FRD body -> NED-like world
            gyro_frd = M_FRD @ d.qvel[3:6]              # body-local angular velocity, NO extra flips
            g_w_sim = np.array([0.0, 0.0, -9.81])
            sf_simbody = R_wb_sim.T @ (d.qacc[0:3] - g_w_sim)   # specific force, sim body
            if args.drop_start_s > 0 and sim_t < args.drop_start_s:
                sf_simbody = R_wb_sim.T @ (-g_w_sim)             # held: looks stationary
            acc_frd = M_FRD @ sf_simbody                # level+rest -> [0,0,-9.81]

            im = hopper_imu_lcmt()
            im.quat = [float(v) for v in R_to_quat(R_frd)]
            im.gyro = [float(v) for v in gyro_frd]
            im.acc = [float(v) for v in acc_frd]
            im.rpy = [float(v) for v in rpy_zyx(R_frd)]
            lc.publish("hopper_imu_lcmt", im.encode())
            next_pub += 0.001

        base_zs.append(d.qpos[2])
        taus_log.append(np.abs(tau_sim).max())
        foot_zs.append(d.qpos[21])
        in_contact = d.sensordata[-1] > 1e-6
        contacts_log.append(1.0 if in_contact else 0.0)

        # Raibert direction probe: at touchdown, does the foot land AHEAD of the
        # hip along the velocity (braking, correct) or BEHIND (accelerating, flipped)?
        if in_contact and not prev_contact and sim_t > args.drop_start_s:
            v_xy = np.array([d.qvel[0], d.qvel[1]])
            foot_off = np.array([d.qpos[19] - d.qpos[0], d.qpos[20] - d.qpos[1]])
            td_events.append((sim_t, v_xy.copy(), foot_off.copy()))
            vn = float(np.linalg.norm(v_xy))
            if vn > 0.03:
                dot = float(v_xy @ foot_off) / vn
                print(f"[TD] t={sim_t:5.2f} v_xy_sim=[{v_xy[0]:+.2f},{v_xy[1]:+.2f}] "
                      f"foot_off_sim=[{foot_off[0]:+.3f},{foot_off[1]:+.3f}] "
                      f"along_v={dot:+.3f} m ({'BRAKE ok' if dot > 0 else 'REVERSED'})",
                      flush=True)

        # per-stance foot slip = integral of the CONTACT-POINT tangential speed.
        # NOTE: the foot geom is a SPHERE -- tracking the foot-center xy would
        # count rolling as slip (and high mu transmits MORE rolling torque, giving
        # slip "increasing" with friction). True slip is the material-point
        # velocity at the contact: v_cp = v_foot + omega_foot x r_cp.
        if in_contact:
            vel6 = np.zeros(6)
            mujoco.mj_objectVelocity(m, d, mujoco.mjtObj.mjOBJ_BODY, foot_bid, vel6, 0)
            omega_w, v_com_w = vel6[:3], vel6[3:]
            # contact point = bottom of the collision sphere, in world coords
            p_cp = d.geom_xpos[foot_gid] + np.array([0.0, 0.0, -foot_r])
            v_cp = v_com_w + np.cross(omega_w, p_cp - d.xipos[foot_bid])
            step_slip = float(np.hypot(v_cp[0], v_cp[1])) * dt
        if in_contact and not prev_contact:
            slip_acc = 0.0
            slip_td_acc = 0.0
            t_td_last = sim_t
            slip_acc += step_slip
            slip_td_acc += step_slip
        elif in_contact:
            slip_acc += step_slip
            if t_td_last is not None and (sim_t - t_td_last) <= TD_WIN:
                slip_td_acc += step_slip
        elif (not in_contact) and prev_contact and sim_t > args.drop_start_s:
            slip_per_hop.append(slip_acc)
            slip_td_per_hop.append(slip_td_acc)
            print(f"[SLIP] t={sim_t:5.2f} stance #{len(slip_per_hop)} slip={slip_acc*1000.0:6.1f} mm "
                  f"(td{TD_WIN*1000:.0f}ms {slip_td_acc*1000.0:5.1f} mm)", flush=True)
        prev_contact = in_contact

        if args.print_roll and int(sim_t / dt) % int(0.2 / dt) == 0:
            R_dbg = quat_to_R(d.qpos[3:7])
            R_frd_dbg = M_FRD @ R_dbg @ M_FRD.T
            r_dbg, p_dbg, _ = rpy_zyx(R_frd_dbg)
            thr_now = [float(d.ctrl[6 + i]) for i in range(3)]
            print(f"t={sim_t:5.2f} roll={np.rad2deg(r_dbg):+6.1f} pitch={np.rad2deg(p_dbg):+6.1f} "
                  f"thrust={thr_now[0]:.1f},{thr_now[1]:.1f},{thr_now[2]:.1f} armed={int(armed[0])}",
                  flush=True)

        if ren is not None and sim_t >= next_frame:
            cam.lookat[:] = [d.qpos[0], d.qpos[1], max(0.5, d.qpos[2])]
            ren.update_scene(d, cam)
            gif_frames.append(ren.render())
            next_frame += 0.04

        if args.realtime:
            lag = (t_wall0 + sim_t) - time.time()
            if lag > 0:
                time.sleep(lag)

    bz = np.array(base_zs)
    ct = np.array(contacts_log)
    n = len(bz)
    third = n // 3
    # longest continuous ground-contact streak AFTER release (stick detector)
    rel_i = int(args.drop_start_s / dt)
    streak = best_streak = 0
    for v in ct[rel_i:]:
        streak = streak + 1 if v > 0.5 else 0
        best_streak = max(best_streak, streak)
    stuck_s = best_streak * dt
    print(f"\nRESULT: {sim_t:.1f}s  base_z min={bz.min():.3f} max={bz.max():.3f} final={bz[-1]:.3f}  "
          f"peak|tau|={max(taus_log):.2f} Nm")
    print(f"late-phase base_z mean={bz[-third:].mean():.3f}  oscillation={bz[-third:].max()-bz[-third:].min():.3f} m  "
          f"contact fraction={ct.mean()*100:.0f}%  max_contact_streak={stuck_s:.2f}s"
          + ("  [STUCK]" if stuck_s > 1.5 else ""))
    if slip_per_hop:
        sp = np.array(slip_per_hop) * 1000.0
        st = np.array(slip_td_per_hop) * 1000.0
        print(f"SLIP: {len(sp)} stances  mean={sp.mean():.1f} mm  median={np.median(sp):.1f} mm  "
              f"max={sp.max():.1f} mm  total={sp.sum():.0f} mm  "
              f"drift_xy={np.hypot(d.qpos[0], d.qpos[1]):.3f} m")
        print(f"SLIP-TD({TD_WIN*1000:.0f}ms): mean={st.mean():.1f} mm  median={np.median(st):.1f} mm  "
              f"max={st.max():.1f} mm  total={st.sum():.0f} mm")
    print(f"THRUST range seen: [{thrust_min_seen:.2f}, {thrust_max_seen:.2f}] N/prop")
    if args.record_gif and gif_frames:
        import imageio.v2 as imageio
        imageio.mimsave(args.record_gif, gif_frames, fps=25)
        print("wrote", args.record_gif)


if __name__ == "__main__":
    main()

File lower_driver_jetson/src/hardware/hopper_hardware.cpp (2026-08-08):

#include "hopper_hardware.hpp"

#include <cstdlib>
#include <string>
#include <thread>

static inline float wrap_to_pi(float a) {
    a = std::fmod(a + static_cast<float>(M_PI), 2.0f * static_cast<float>(M_PI));
    if (a < 0.0f) a += 2.0f * static_cast<float>(M_PI);
    return a - static_cast<float>(M_PI);
}

// ===== Delta leg motor ordering (REAL ROBOT) =====
// We publish/consume the delta leg motors on LCM as q[0],q[1],q[2] and tau_ff[0],tau_ff[1],tau_ff[2].
// This array maps that **LCM joint index** -> **AK60 motor_id** (0..2).
//
// IMPORTANT:
// - Keep this mapping consistent for BOTH: sending commands AND reading states.
// - If your wiring / CAN IDs differ, change this array (do not scatter swaps across the file).
//
// LCM joint index rotation (2026-06-24), applied twice at LCM source:
//   1st: q0<-q2, q1<-q0, q2<-q1  => {2,0,1}
//   2nd: same rule again           => {1,2,0}
//   (2026-06-27) identity mapping {0,1,2}: LCM q0->motor 0, q1->motor 1, q2->motor 2
static constexpr int kDeltaAk60MotorIdFromJointIdx[3] = {0, 1, 2};
// LCM q = -motor_pos + offset. Full extension -> q_lcm = 0 when motor_pos = offset.
static constexpr float kAk60LcmQOffsetRad = -1.047f;  // -60 deg (CASE hopperHFAcase2026)

HopperHardware::HopperHardware(bool is_publish_lcm_data):
        Controller2Robot("udpm://239.255.76.67:7667?ttl=255"),
        Robot2Controller("udpm://239.255.76.67:7667?ttl=255"),
    lcmreceiveTask(&task_manager_, 0.001, "lcmrecv_task", &HopperHardware::_thread_lcmrec_run, this),  // 1000Hz receive (drains ALL pending msgs per tick)
    lcmsendTask   (&task_manager_, 0.001, "lcmsend_task", &HopperHardware::_thread_lcmsen_run, this),  // 1000Hz send
    imuTask       (&task_manager_, 0.001, "imu_task", &HopperHardware::_thread_imu_run, this),           // 1000Hz IMU publish
    gamepadTask   (&task_manager_, 0.005, "gamepad_task", &HopperHardware::_thread_xbox_run, this),   // 200Hz gamepad
        motor_pos(3, 0.0),
        motor_vel(3, 0.0),
        motor_tau(3, 0.0),
        motor_vel_diff(3, 0.0),
        motor_pos_prev(3, 0.0)
{
    this->is_publish_lcm_data = is_publish_lcm_data;
    set_value_zero(); // clear all the value
    // initialize the leg motor controller (3x AK60 over SocketCAN / can0)
    ak60_controller_ptr_ = new AK60Controller();
    rot_offset_ = coordinateRotation(CoordinateAxis::Z, 0.0f)
                * coordinateRotation(CoordinateAxis::Y, 0.0f)
                * coordinateRotation(CoordinateAxis::X, 0.0f);
    // initialize the Lpms IG1 IMU (same as CASE hopper_driver-master)
    // 2026-07-09: run the IG1 at 500 Hz (factory default streams 100 Hz, which
    // held every gyro/rpy sample for ~5 control ticks). 500 Hz does not fit in
    // 115200 baud, so the sensor UART is converted to 921600 and the payload
    // trimmed to the fields this driver consumes.
    imu_wrapper_ptr_ = new ImuWrapper();
    {
        const uint32_t kImuTdrMask =
            TDR_ACC_CALIBRATED_OUTPUT_ENABLED |
            TDR_GYR1_BIAS_CALIBRATED_OUTPUT_ENABLED |   // parsed as gyroIIBiasCalibrated
            TDR_QUAT_OUTPUT_ENABLED |
            TDR_EULER_OUTPUT_ENABLED;
        const int kImuTargetBaud = LPMS_UART_BAUDRATE_921600;
        // Probe target baud first (sensor already converted on a previous run),
        // then factory default, then intermediates in case a conversion half-landed.
        const int bauds[] = {kImuTargetBaud, LPMS_UART_BAUDRATE_115200,
                             LPMS_UART_BAUDRATE_460800, LPMS_UART_BAUDRATE_230400};
        const char* env_port = std::getenv("HOPPER_IMU_PORT");
        std::vector<std::string> ports;
        if (env_port != nullptr && env_port[0] != '\0') ports.push_back(env_port);
        ports.push_back("/dev/ttyUSB0");
        ports.push_back("/dev/ttyUSB1");
        // NO ttyACM* fallback: since 2026-07-23 /dev/ttyACM2 is the wheel-bus
        // CANable2 (see 99-canable.rules), and the IG1 baud probe wedges its
        // CDC endpoint (write -> EIO until USB re-enumeration). If the IG1 is
        // ever attached over ACM again, point HOPPER_IMU_PORT at it.

        std::string imu_port;
        int imu_baud = 0;
        for (const std::string& p : ports) {
            for (int b : bauds) {
                if (imu_wrapper_ptr_->connect(p, b)) {
                    imu_port = p;
                    imu_baud = b;
                    break;
                }
            }
            if (imu_baud != 0) break;
        }
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

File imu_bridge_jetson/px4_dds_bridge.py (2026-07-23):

#!/usr/bin/env python3
"""px4_dds_bridge: PX4 <-> LCM bridge over uXRCE-DDS (TELEM2).

DOWNLINK (IMU): read PX4 attitude/IMU DDS topics and publish hopper_imu_lcmt --
the high-rate, contention-free replacement for the IMU half of px4_bridge.py.

UPLINK (props, 2026-07 "Plan B"): subscribe motor_pwm_lcmt on LCM and stream the
prop throttles to PX4 as VehicleCommand DO_SET_ACTUATOR (187) on
/fmu/in/vehicle_command -- the SAME command the USB MAVLink path sends, only the
transport changed. With this enabled the USB link carries nothing critical and
can be unplugged; run px4_bridge with --no-props to avoid double-streaming.

2026-07-06 BIDIRECTIONAL (DShot 3D): props moved to AUX1/2/3 as DShot600 with
PX4 DSHOT_3D_ENABLE=1 and AM32 3D mode saved in ESC EEPROM. The pwm convention
on motor_pwm_lcmt is now: 1000us = stop, >1000 = forward (same scale as before),
<1000 = reverse. See --bidir / _actuator_vals for the mapping details.

Why DDS instead of MAVLink-over-USB:
  The single USB-MAVLink link had to carry BOTH the IMU stream and the prop
  MAV_CMD_DO_SET_ACTUATOR stream, so the prop rate was capped (~150Hz because
  PX4 ACKs every command_long on the same link). TELEM2 at 3 Mbaud is dedicated
  and we simply never subscribe the DDS ack topic, so no ACK flood exists here.

Topics consumed (PX4 1.14 defaults, BEST_EFFORT QoS):
  /fmu/out/vehicle_attitude   VehicleAttitude  q=[w,x,y,z] body(FRD)->NED
  /fmu/out/sensor_combined    SensorCombined   gyro_rad, accelerometer_m_s2 (body FRD)

  Pure FRD pipeline (single proper rotation, no reflections):
      R_base  = R_ENU_NED @ R_fc @ R_mount^T
      R_wb    = R_base @ Rx(180deg)      # make body +Z point world-down
      gyro    = Rx(180deg) @ (R_mount @ raw gyro)
      acc     = Rx(180deg) @ (-(R_mount @ raw accel))
  quat/rpy/gyro/acc are all derived from this same FRD frame.

Official PX4 raw (see PX4 docs + mount_calibrate.py):
  board FRD (+X arrow, +Y right, +Z down); VehicleAttitude.q = board->NED; SensorCombined in board FRD.
Physical vertical mount: acc_b~[-g,0,0] at level => R_mount = Rz(psi)*Ry(+90deg) => mount_rpy = 0,90,psi.
This airframe: board Ry(+90deg) then Rz(+90deg) => mount_rpy = 0,90,90.
Live sign calibration: this mount gives the correct pitch direction; the displayed
rpy roll/yaw signs are flipped below to match the operator convention.
If X/Y still swapped after a mechanical change, re-run mount_solve.py (psi only).

Canonical transform matches pixhawk/px4_bridge.py (MAVLink path).

Run:
  source /opt/ros/humble/setup.bash
  source ~/px4_ws/install/setup.bash
  ROS_DOMAIN_ID=0 python3 px4_dds_bridge.py
"""
import os
import sys
import math
import time
import argparse
import threading

import rclpy
from rclpy.node import Node
from rclpy.qos import QoSProfile, ReliabilityPolicy, DurabilityPolicy, HistoryPolicy

from px4_msgs.msg import VehicleAttitude, SensorCombined
try:
    from px4_msgs.msg import VehicleCommand  # uplink: DO_SET_ACTUATOR over DDS
except Exception:  # pragma: no cover - old px4_msgs build without VehicleCommand
    VehicleCommand = None
try:
    # RM C610/M2006 relay (custom rm_c610 PX4 module, 2026-07). Needs the two
    # Rm*.msg files copied into ~/px4_ws/src/px4_msgs/msg + colcon rebuild.
    from px4_msgs.msg import RmEscCommand, RmEscStatus
except Exception:  # pragma: no cover - px4_msgs build without the Rm messages
    RmEscCommand = None
    RmEscStatus = None


def _add_lcm_type_paths():
    here = os.path.dirname(os.path.abspath(__file__))
    candidates = [
        os.environ.get("HOPPER_LCM_PY", ""),
        os.path.join(here, "..", "hopper_lcm_types", "lcm_types", "python"),
        os.path.expanduser("~/Hopper_srbRL/hopper_lcm_types/lcm_types/python"),
        os.path.expanduser("~/Hopper_srbRL/rl_deploy/lower_lcm/lcm_types/python"),
    ]
    for c in candidates:
        if c and os.path.isdir(c) and c not in sys.path:
            sys.path.insert(0, c)


_add_lcm_type_paths()
import lcm  # noqa: E402
from hopper_imu_lcmt import hopper_imu_lcmt  # noqa: E402
try:
    from motor_pwm_lcmt import motor_pwm_lcmt  # noqa: E402  (prop uplink)
except Exception:  # pragma: no cover
    motor_pwm_lcmt = None
try:
    from rm_esc_cmd_lcmt import rm_esc_cmd_lcmt    # noqa: E402  (M2006 uplink)
    from rm_esc_data_lcmt import rm_esc_data_lcmt  # noqa: E402  (M2006 downlink)
except Exception:  # pragma: no cover - lcm-gen not run yet for the rm types
    rm_esc_cmd_lcmt = None
    rm_esc_data_lcmt = None

DEG = math.pi / 180.0
RAD = 180.0 / math.pi


# ---- rotation helpers ----
def _rx(a):
    c, s = math.cos(a), math.sin(a)
    return [[1, 0, 0], [0, c, -s], [0, s, c]]


def _ry(a):
    c, s = math.cos(a), math.sin(a)
    return [[c, 0, s], [0, 1, 0], [-s, 0, c]]


def _rz(a):
    c, s = math.cos(a), math.sin(a)
    return [[c, -s, 0], [s, c, 0], [0, 0, 1]]


def _matmul(A, B):
    return [[sum(A[i][k] * B[k][j] for k in range(3)) for j in range(3)] for i in range(3)]


def _matvec(A, v):
    return [A[i][0] * v[0] + A[i][1] * v[1] + A[i][2] * v[2] for i in range(3)]


def _transpose(A):
    return [[A[j][i] for j in range(3)] for i in range(3)]


# PX4 world is NED; controller / ModeE world is +Z up (ENU-style).
R_ENU_NED = [[0, 1, 0], [1, 0, 0], [0, 0, -1]]
R_FRD_FIX = _rx(math.pi)
# User-requested extra SO(3) rotation: right-hand +Z axis, +180 deg.
# Keeps Z-down unchanged while flipping X/Y directions.
R_USER_Z180 = _rz(math.pi)

def quat_to_R(q):
    w, x, y, z = q
    return [
        [1 - 2 * (y * y + z * z), 2 * (x * y - w * z), 2 * (x * z + w * y)],
        [2 * (x * y + w * z), 1 - 2 * (x * x + z * z), 2 * (y * z - w * x)],
        [2 * (x * z - w * y), 2 * (y * z + w * x), 1 - 2 * (x * x + y * y)],
    ]


def euler_to_R(roll, pitch, yaw):
    return _matmul(_rz(yaw), _matmul(_ry(pitch), _rx(roll)))
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

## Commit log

2026-07-07 Initial commit: Hopper robot_runtime (Jetson driver, PC ModeE controller, RL/sim, services)
    [Foot_Link.STL, Leg_Link.STL, base_link.STL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]
2026-07-07 Strengthen stance gyro filter (notch BW 32Hz, LPF 15ms); make LT/RT RM-only triggers (LT: drive at next push end, RT: standalone P4 stand + RT job)
    [lcm_controller.py]
2026-07-07 Add Mode 3: HLIP step-to-step foot placement with per-hop measured Ts/z0 (closed-form deadbeat-family gain, replaces hand-tuned Raibert kv); numerical validation script
    [modee_fake_robot.py]
2026-07-08 Mode 3 fix + friction-cone downforce experiment (sim)
    - core.py: fix HLIP S2S z0 sign (world +Z down -> pivot height was negative,
    gain stayed NaN and mode 3 silently fell back to Raibert; 3D sim now
    survives 15s with the derived gain 0.2-0.37)
    - core.py: stance_downforce_n friction-cone modulation (prop collective
    reverse + leg fz raised by the same amount), TD-window gating
    (stance_downforce_td_s) and lever-feedforward exclusion after sim showed
    full-stance downforce backfires through fxy ~ rx*fz/rz
    - sim: --floor-mu, bidirectional thrust (pwm<1000 reverse), true
    contact-point slip metric (per-stance + TD-window), --drop-z,
    _run_frictioncone_sweep.sh mu x downforce A/B harnes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
    [lcm_controller.py, modee_fake_robot.py]
2026-07-08 Strengthen stance D-term gyro filter: second notch at the measured 13 Hz touchdown-ring band
    Pure-leg log spectrum showed 57% of stance gyro_x noise in 8-20 Hz (impact
    ring), which the 25 Hz notch barely attenuates. Cascade a 13/10 Hz notch and
    pull the LPF back 15->8 ms: residual D-term noise 0.28->0.21 (x) / 0.17->0.11
    (y) rad/s on log replay, 3 Hz phase lag only 24->28 deg.
2026-07-08 IMU 500 Hz: LPMS-IG1 stream freq 100->500, sensor UART 115200->921600, trimmed TDR payload
    - ImuWrapper: bounded connect timeout (baud probing must fail fast),
    configureStreaming(freq, tdr_mask) + setUartBaudrate() with queue-drain waits
    - hopper_hardware: probe 921600/115200/460800/230400, convert sensor UART
    before raising the rate, pick stream rate the link can carry (500/250/100),
    print measured rate at startup
    - regenerate stale committed LCM C++ types from current .lcm defs
    (per-file lcm-gen, no bogus lcmtypes namespace)
    [ImuWrapper.cpp, hopper_hardware.cpp]
2026-07-09 Stance tuning for the 400Hz IMU chain: fxy cap 30->20N (single cone+ceiling), stance D-term gyro unfiltered, body-frame GRF logging
    - core: stance_fxy_max 20N (measured hops peak ~19N; cone mu*fz still guards TD)
    - core: stance gyro notch/notch2/LPF zeroed (user: no filtering now that fresh
    gyro is 400Hz instead of 100Hz held 5 ticks; path kept, re-enable via config)
    - lcm_controller: log f_contact_b0..2 (controller's own body-frame GRF)
    - plot_hops: one continuous timeline (log time, all hops, stance shaded),
    body-frame forces read from f_contact_b when present
2026-07-09 stance attitude: 10ms delay predictor (Smith-style), kR 30->50 kW 1.3->3, cone mu 0.08->0.25
    Grey-box ID on 09:5x log: cmd->response delay 10ms; SIMC for double
    integrator + delay explains the empirical kW~1.4 ceiling. Predictor
    extrapolates e_R by omega*T and omega by (T/J)*tau_prev, buying gain
    headroom. Cone mu raised: early-stance fxy was riding the 0.08*fz limit
    (cone clipping, not weak gains). Sim A/B: TD slip 69->43mm, drift
    0.57->0.34m, kW=3 stable.
2026-07-09 fix predictor chatter (ring-buffer Smith predictor); hard-isolate sim LCM to port 7669
    v1 predictor weighted the LAST torque by the whole 10ms horizon (5x) ->
    per-step loop gain kW*T/J~1.0 -> Nyquist sign-alternating fxy chatter on
    hardware (10:27 log). Now each in-flight command carries its true dt/J
    impulse via a ring buffer, cone-scaled to the delivered torque, with a
    +-3 rad/s robustness clip. Sim: sign-alt 7%, |dF/step| 0.12N.
    Sim scripts default to udpm 7669 ttl=0 (real bus is 7667): ttl=0 alone
    does not prevent same-host cross-talk into a running run_modee session.
    [cao_fake_robot.py, modee_fake_robot.py]
2026-07-09 modes: 1 = legacy stance PD (A/B baseline); 2/3 = stance attitude upgrades
    Mode 2/3 stance attitude now uses three paper-standard structures:
    (1) model-based rate filter (steady-state KF: predict omega with
    J*domega = tau_prev, blend gyro with stance_att_kf_k=0.3)
    (2) touchdown reference shaping (cubic Hermite from (e_td, omega_td)
    to (0,0) over stance_att_ref_T=0.12s + J*alpha_ref feedforward)
    (3) error-scheduled damping (kW ramps stance_kpd -> stance_kpd_high=3
    as |e_R| grows past stance_nl_e0_rad=0.05)
    Mode 1 keeps the exact pre-upgrade plain PD. New CSV debug columns
    att_e_ref / att_kw_eff / omega_kf. CAO_MODE=1 shim removed (now legacy
    PD, use CAO_PURE=1 for leg-only). Added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
    [lcm_controller.py]
2026-07-10 bench: tri-rotor system-ID scripts (thrust ladder / lag step / chirp FRF)
    bench_prop_id.py streams motor_pwm_lcmt experiments (collective ladder on a
    scale, differential steps and log-chirp on the gimbal) while logging IMU +
    commanded PWM to CSV; requires --yes-spin, always ramps down + disarms.
    bench_prop_fit.py fits k_thrust (+ battery-voltage slope), motor time
    constant tau_m, control effectiveness, and the empirical attitude FRF
    (-3dB / -90deg crossover). Validated on synthetic data.
2026-07-10 flight prop gains: cut kR 90->45 kW 35->14, tau cap 25->8 (bench-measured)
    Gimbal bench data (bench_step_0710_180657 + modee_latest): motor time
    constant ~105 ms; at 90/35 the flight attitude loop limit-cycled at ~8 Hz
    with 37% PWM railing. Gains now sized to the measured actuator lag;
    static bench pitch offset is a pivot-offset gravity moment (bench
    artifact, not present in flight).
2026-07-10 props: raise flight base thrust 0.02->0.25 m*g, no reverse in flight
    At the old 0.25 N/arm idle any attitude differential crossed zero ->
    constant ESC forward/reverse flips around level (a direction change
    through 1000us is the slowest thing the ESC does). Base now ~3 N/arm
    (pwm ~1170): +-3 N symmetric authority with no direction change and a
    steeper sqrt working point. Flight allocation gets a no_reverse floor
    (large torques use collective lift instead of reversing the low arm);
    stance keeps the bidir floor for the downforce path.
2026-07-10 props: rescale all thrust/torque params for calibrated k=1.24e-5
    Old k=1.10e-4 was ~9x optimistic: mapping delivered only ~11% of the
    commanded torque. With k fixed the same PD numbers would raise the
    physical loop gain 9x, so everything is rescaled to keep the delivered
    behavior honest: flight kR/kW 45/14 -> 8/3 (~= old physical loop minus
    margin), flight tau cap 8 -> 1.5 Nm (real authority at base 0.15),
    stance prop overlay 10/10 -> 1.2/1.2, per-arm cap 55 -> 4.5 N,
    total ratio 3.5 -> 0.36, reverse budget 10 -> 1.1 N, pwm_max 1700 ->
    1600 (calibration data ends at 1500).
2026-07-10 props: base lift 0.15->0.08, flight gains 8/3 -> 18/5 (gimbal log review)
    19:00 gimbal log at 8/3: loop is clean (no limit cycle, 0.4us/tick pwm
    jitter) but too weak -- roll parked at +6.2 deg = P-only steady error
    against the ~0.9 Nm pivot-offset gravity moment, tau_des railed at the
    1.5 Nm cap 36% of the time. Allocation itself verified correct: delivered
    body torque tracks the demand exactly (the apparent sign flip was the
    yaw~180 world/body comparison) and correlates restoring with e_R.
    Base cut to 8% lift per user (15% constant lift hurts hop energy).
2026-07-10 flight prop gains 18/15 -> 10/4: 6.4 Hz saturation limit cycle on gimbal
    19:06 log: tau_des railed at the 1.5 Nm cap 67%, pwm3 on the floor 49%,
    roll parked +10.4 deg. kW=15 with a 105 ms actuator is positive feedback,
    and the gimbal pivot moment (~1 Nm) eats 2/3 of total prop authority so
    strong gains bang-bang between the rails. Further flight-gain tuning
    requires counterweighting the gimbal level first.
2026-07-10 flight props: allow reverse above |e_R|>=0.08 rad, forward-only near level
    Log at +17 deg: pwm3 stuck on 1090 forward floor, pwm2 pegged 1497, no arm
    reversed because prop_flight_no_reverse blocked bidir. Hybrid policy: small
    angles stay forward-only (no 1000us flips); large errors use bidir so the low
    arm can reverse for more differential authority without collective-lift
    saturation.
2026-07-10 props: feasibility-based auto reverse policy (replaces |e_R| threshold)
    Prioritized (daisy-chain) allocation: solve forward-only first, open the
    reverse floor only when that solution cannot realize the demanded torque
    (allocator s<1), with a hysteresis latch that disengages when the bidir
    solution returns to the forward side -- no flip-flopping across 1000us.
    Criterion is actuator feasibility instead of an arbitrary angle cut.
    flight_tau_rp_max 1.5->2.5 (must exceed the forward-only ceiling ~2 Nm,
    else reverse never engages; bidir ceiling ~3 Nm, verified numerically).
2026-07-10 stance attitude: delete ALL filtering/shaping, plain PD on raw gyro everywhere
    Removed per user request (real physics only): dual gyro notches + LPF,
    model-based KF rate filter, touchdown Hermite reference shaping,
    error-scheduled damping, and their config/state/debug-log columns.
    All modes now use tau = -kR*e_R - kW*omega_raw in stance.
    [lcm_controller.py]
2026-07-10 stance PD: kR 50->20, kW 0.5->1.5 (pole placement, zeta~1 critical damping)
    20:27 log: hop-to-hop divergence driven by liftoff RATE (w_LO*Tf ~ -24 deg
    vs e_LO +8 deg). Underdamped stance PD left the ground still rotating;
    critical damping minimizes residual rate at LO.
2026-07-10 vel KF: match meas noise to measured reality (0.12->0.30, push 0.50); prop_vel_tilt uses KF v_hat
    Offline replay of the 20:33 log: the old 0.12 std made the KF chase
    0.5-0.9 m/s rms leg-kinematics bursts inside stance; the residual at LO
    flew as phantom drift (fl7 0.24->0.07 m/s with the fix). The remaining
    mid-flight velocity (up to 1 m/s) is REAL, produced by stance attitude
    side forces (~20N x 0.18s), i.e. an attitude problem, not estimation.
2026-07-10 flight foot placement: x bias 0 -> +0.05 m (cancel one-signed nose-up fz lever)
    22:10 log: fz-weighted stance-mean rx = -3..-9 cm every hop, pitch lever
    impulse -0.5..-1.7 Nms/hop -> flight pitch +7..+16 deg on every flight.
    The swing leg mirrors that tilt (world-vertical placement), which is the
    'big leg swing at small velocity' the user sees.
2026-07-10 delete qd conditioning chain (EMA+MA+LPF): raw CAN qd into kinematics
    Per user: no signal filtering on the leg-side body velocity path. The
    velocity KF (meas_std matched to real noise) is the single place
    measurement noise is handled.
2026-07-10 revert AK60 LCM q offset +90 -> +85 deg (and matching safe_q_max)
    [hopper_hardware.cpp, lcm_controller.py]
2026-07-10 add inverted-pendulum-paper style rate observer for stance kW (model-predict with commanded torque, gyro correction) to allow high D without chatter
2026-07-10 lower touchdown threshold 2cm -> 1cm per user to shrink contact-to-flag blind window
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2026-07-10 move forgetting-factor filter to a dedicated body-velocity measurement channel; control-side qd stays raw
2026-07-19 consolidate the hopping runtime around the proven Mode1 controller
    Remove unreachable mode allocators and mode-selection switches so tuning, simulation, and diagnostics all describe the hardware-tested control path without changing its outputs.
    [three_leg_3rsr_closed.xml]
2026-07-20 energyfail
    Revert the MATLAB Kp*(E_des-E) stance energy pump and restore the Mode1
    push-spring law from 2aa050e after the additive pump over-compressed and
    chattered.
2026-07-20 Add FB-SLIP Mode1 Z planning with dual force budgets and ballistic guards.
    Single-knob hop_height constant-force stance, flight prop Z sum cap, t_bottom
    PUSH gate, and per-hop ballistic v_td floor so weak kinematic estimates cannot
    latch PUSH early. Log archive: modee_fbslip_20260721_0359.csv (local, gitignored).
    [lcm_controller.py]
2026-07-23 Add Kiwi mobile mode, FB-SLIP v3 energy shaping, and RT stand-and-unfold transition
    - Kiwi drive: wheel_cmd_lcmt type, DM-H6215 SocketCAN driver, upper-side
    inverse kinematics and gamepad mapping.
    - Stance control: continuous energy-deficit shaping (no discrete sink
    state), additive apex energy bias adaptation, vertical KF channel with
    stance anchoring and ballistic flight propagation.
    - LT: post-push stand-and-fold to MOBILE (props off, leg carries stand).
    - RT: P4 places the leg, then uncapped inverted-pendulum stand while RM
    arms unfold synchronized (fast waits for slow); hopping starts in
    plain FLIGHT with no first-hop spring/l0 override.
    [ak60_controller.h, dm_wheel_controller.h, hopper_hardware.cpp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]
2026-07-25 Positional reception + latched constant push for reliable hop energy delivery
    Reception: spring stays below body weight until the 4.5 cm travel target
    (gravity guarantees the sink through linkage impact/friction losses), then
    catches at the full leg budget within 1.5 cm. PUSH: constant force sized
    once at the bottom latch and held open-loop, with the blend entering from
    below only, so neither the ringing vz estimate nor the catch force leaks
    into the push. Props: COMP base 1400 us, PUSH 1700 us in all height modes;
    flight leg PD velocity low-passed to kill the 30 Hz swing chatter.
    Plot tool gains a leg-length/compression panel.
    [lcm_controller.py, modee_fake_robot.py]
2026-07-25 Add depth terrain gate (FLAT/SLOPE/STEP/BLOCKED) and Jetson D435 net stream.
    Include design-map compression target telemetry for FB-SLIP hops, plus live
    viewer/tools so the PC can classify ground from the camera on the Jetson.
    [lcm_controller.py]
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2026-08-01 Prop energy supplement persists through the ascent with a continuous apex fade; add control framework doc
    The supplement force is sized over the push stroke PLUS the ascent
    (F = E_def/(x0+h_tgt)) and in flight rolls off as clip(vz_up/0.3, 0, 1) --
    zero exactly at apex, no switch. Apex overshoot from the ascent share is
    absorbed hop-to-hop by the apex return map. docs/CONTROL_FRAMEWORK.md
    writes down the whole architecture: phases, dual energy paths, SO(3)
    attitude split, idle-base differential allocator, Raibert + PogoX velocity
    loop, the no-hard-cut inventory, and the tuning table.
2026-08-01 NRC continuous stance energy law (ACC 2020) with prop fusion and height coupling
    One smooth norm-regulation force law replaces the Mode1 PUSH latch for the
    whole stance (no latch, no k re-solve, no blend): energy converges inside a
    single stance and the pump force is zero at the bottom, killing the 130->430 N
    f_z jump behind the tau chatter. Height target enters through the norm radius
    r* = |(m*g_st/k, v_to/w)|; the leg-cap residual rides the prop collective
    continuously, and in flight the props regulate the same apex target via
    ballistic prediction error with the vz apex fade. Mode1 stays selectable via
    stance_energy_law="mode1".
    [lcm_controller.py]
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2026-08-01 Fix systemd deadlock: optional wheel-bus CANable no longer blocks hopper-driver
    With the can1 adapter unplugged, canable2.service (pulled at boot via
    multi-user.target, BindsTo=dev-canable2.device) parked a device job that
    never completes, and hopper-driver's Wants+After ordering deadlocked every
    (re)start behind it -- connect_and_start hung after the unit-install step.
    canable2 is now hot-plug only (WantedBy=dev-canable2.device), hopper-driver
    drops the Wants=, and the script syncs + reenables both units.
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2026-08-01 Prop PWM ceiling is 1950 us, and make the per-arm thrust cap match it
    The per-arm 10 N cap dated from k = 1.24e-5, where it sat near 1900 us.
    After the thrust-stand recalibration to k = 2.25e-5 the same 10 N is only
    1667 us, so that stale number -- not the PWM ceiling -- was binding: every
    recent log shows all three arms pinned at exactly 1667. Sets the hardware
    maximum to 1950 us per the user and raises the per-arm cap to the matching
    20.3 N, leaving thrust_total_ratio_max (0.60 mg = 39.4 N) as the real
    collective budget.
2026-08-01 Strengthen 3-rotor flight velocity convergence gains
    Raise flight_vel_kv 4->7, tilt max 12->18 deg, slew 120->180 dps, and
    trim the level-settle margin 0.14->0.12 so short flights still get lean
    authority. Attitude PD / per-arm differential room already bumped.
2026-08-01 Tune apex to 7cm target: cut flight apex-feedback gain, stiffen NRC spring
    Log 070306 apexes hit 13.5/18.1cm vs 7cm: prop_height_kh=1.0 turned a few
    cm of absolute-height drift into the same overshoot via 5-19N of flight
    collective; 0.4 only rescues large shortfalls (1D sim: apex 6.7cm).
    nrc_k_n_m 1400->2200 shallows compression and shortens stance.
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2026-08-01 Fix apex overshoot: soften NRC pump, fade it at extension, close loop on measured apex
    Log 073212 hopped ~0.15 m against the 0.07 m target with r still below
    r* at liftoff: the stance vz estimate lags 25-50 ms, and at kR=400 the
    pump (coefficient 2*m*kR*omega ~ 88e3) keeps 100+ N firing after the
    true energy has crossed the target. Three-part fix, sim-verified to
    converge to 7.0 cm in 3-4 hops under 25-70 ms lag or 20% vz bias:
    - nrc_kR 400 -> 150 (overshoot scales with kR * estimator lag)
    - pump *= clip((l0-h)/nrc_pump_ext_fade_m, 0, 1): smooth roll-off over
    the last 4 cm of extension where residual pumping turns into apex
    - per-hop apex return map (Koditschek-Buehler layer for NRC): the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
    [lcm_controller.py]
2026-08-01 Fix apex overshoot: NRC pump was over-injecting through a lagged vz estimate
    Log 073212: at push end the NRC state read r/r*=0.82 while the true
    liftoff vz was already 1.32 m/s vs the 1.166 target -- the pump reads a
    ~30 ms stale velocity, thinks the energy is short, and keeps injecting.
    A lag-in-the-loop sim reproduces the logged 11+ cm apex on the 7 cm
    setpoint at kR=400. nrc_kR 400->250 and stance_vz_lpf_tau_s 15->8 ms
    sim at 6.6 cm and cut lag sensitivity 2.6x.
2026-08-01 Restore per-hop apex return map + pump fade; add 8ms vz LPF
    Commit 9bf5fbb accidentally reverted de78e19 (the worktree had been
    rolled back under it). This restores the full apex-overshoot fix --
    kR=150, pump extension fade, per-hop apex trim (nrc_h_trim) -- and
    keeps the 8 ms stance vz LPF on top. Lag-in-the-loop sim: converges
    to 7.0 cm in 3-4 hops under 30 ms lag and/or 20% vz bias.
2026-08-02 Restore pump strength (kR 150->350) now that fade+trim absorb the overshoot
    Log 080815: at kR=150 the first stance peaked at 133 N total demand --
    spring only, 3 N residual for the props, no liftoff. The extension
    fade and per-hop apex trim added in de78e19 are what actually contain
    the lag-induced overshoot, so the pump no longer needs to be weak:
    sim at kR=350 with 30 ms lag launches cold, props saturate 39 N every
    hop, apex 10.6 -> 8.1 -> 7.4 -> 7.0 cm in 4 hops.
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2026-08-02 Horizontal velocity convergence: two-layer structure synced to the height knobs
    - Raibert placement is now the textbook return-map law p = (T_st/2)*v +
    flight_kv*(v - v_des): the neutral point (pi/2)*sqrt(m/nrc_k_n_m) is
    computed live from the stance stiffness, flight_kv (0.17->0.08, same
    total braking) becomes the pure feedback gain, and v_des enters with
    the correct Raibert sign (flight_kr feedforward retired).
    - Descent velocity-brake collective (prop_descent_brake_ratio=0.10):
    the tilt's lateral force is Fz*tan(theta) and descent Fz was the
    0.68 N idle -- 18 deg delivered 0.2 N. Error-gated, faded on the
    same time-to-touchdown clock as the tilt budget.
    - New telemetry fl_e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
    [lcm_controller.py]
2026-08-02 Hybrid prop assist for leg 9 Nm torque cap; revert stance Z to foot kinematics
    Proportional tau scaling routes undeliverable Fz/attitude residual to the
    props in stance; flight keeps attitude-only collective. Stance Z velocity
    stays planted-foot (CASE-style pure IMU Z drifted and collapsed mid-push).
    Also restore TELEM2/DDS Pixhawk reboot helper.
    [lcm_controller.py]
2026-08-02 Prop idle at PWM 1500 with attitude-only mode; FB-SLIP stance and Fz plot.
    Pin collective to 1500us, disable prop energy/descent-brake Fz paths, and
    keep differential for attitude. Stance defaults to the FB-SLIP port with
    leg/prop Fz split knobs; plot_torque_fz shows prop residual vs leg Fz.
    [lcm_controller.py]
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2026-08-05 Add RM2006 wheels, link-loss DAMP, and Jetson upper deploy.
    Replace Damiao hub motors with RM2006/C610 local speed PI on can1,
    force DAMP when hopper_cmd is stale >200ms, align AK60 LCM q offset
    to CASE (-60 deg), and add sync_upper/fetch_plot helpers so the upper
    layer can run on Jetson with the PC as remote start/stop/monitor.
    [hopper_hardware.cpp, hopper_hardware.hpp, main.cpp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]
2026-08-05 Enable pogox apex trim, encoder TD gate, and quieter stance pump.
    Wire the hop-to-hop apex return map into pogox so measured flight-time
    apex drives h*, accept TD when the encoder shows real compression even
    if world vz is drifted, and filter/slew the pump path; plot apex from
    the drift-free flight-time measurement.
    [lcm_controller.py]
2026-08-05 Unlock hop-height ceiling: raise trim max, disable pump hard-cut.
    Log 205009 pinned apex at 3-4.5 cm because nrc_apex_trim_max=1.6 and
    the pump slew wall choked energy inject. Raise the trim ceiling to 2.5,
    start trim at 1.4 to skip cold-start undershoot, and turn off pump
    output slew so smoothness comes from the vz input filter -- the model
    itself, not a max cut, should track the hop_height knob.
2026-08-05 Fix inverted apex feedback: anchor pogox spring to the height knob.
    The apex trim scaled the same h* that designs k_v, but the
    stroke-anchored spring ties omega to v*, so v*/omega tends to the
    stroke X and r* barely moved (+11%) while the leg stiffened 54%.
    A stiffer leg compressed less on the same landing speed, so raising
    the trim REDUCED energy per hop -- log 212547 decayed 3.45 to 1.79 cm
    while trim railed 1.56 to 2.50. Split the target: k_v follows the
    hop_height knob (plus the one-shot RB boost) and only r* takes the
    trim, matching the nrc law's existing fixed-stiffness structure.
2026-08-05 Gate the flight velocity damper to the ascent so landings are level.
    The lean was bounded by a budget built from a predicted time-to-touchdown;
    when the previous hop's airtime ran long the budget never tightened and
    the lean sat at the 10 deg cap until contact, where the stance branch
    zeroed the slew state and stepped R_des by 10 deg (log 004804 TD2, body
    4.8 deg off and still rotating at touchdown). Command level once apex is
    crossed instead: apex is observed from the vz sign change, so the
    slew-limited ramp always finishes first -- replaying that flight the lean
    reaches zero 40 ms before contact. Enable the damper by default.
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2026-08-08 Revert hopping fall-rate propeller rescue.
    Keep the feature in git history from the previous commit, but remove the
    contact-timing fall-rate rescue from the live hopping controller.
    [lcm_controller.py]
